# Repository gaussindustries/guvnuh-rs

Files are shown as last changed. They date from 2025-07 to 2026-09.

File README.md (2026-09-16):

# Guv'nuh — Micro-Grid Governor Control Platform

A Rust, bare-metal-to-browser control system for a laboratory micro-grid generator set. A hard-real-time STM32H753 governs the machine; an ESP32 bridges it to a Dioxus server and a desktop operator console. Built as the engineering centerpiece for [Gauss Industries](https://gaussindustri.es).

---

## What it does

Guv'nuh closes the loop on a self-excited induction generator (SEIG) driven by a variable-speed prime mover: it holds speed and frequency against changing electrical load, sheds load safely on fault, and streams a full electrical picture — per-phase voltage and current, real power, power factor, DC-bus state — to an operator in real time.

The architecture follows one principle: **the STM32 runs the machine; everything else observes and commands.** Safety-critical decisions (overspeed, load rejection, over-voltage/current) are computed and acted on locally, on-device, with no dependence on the network being up. The ESP32 relays; the server stores; the terminal analyzes. Comms can drop without the machine ever losing control.

---

## System architecture

```
  ┌─────────────┐   UART/COBS    ┌──────────┐    TCP/COBS    ┌──────────────┐   HTTP    ┌───────────────┐
  │  STM32H753  │◄──────────────►│  ESP32   │◄──────────────►│ Dioxus Server│◄─────────►│ Desktop Term. │
  │  (RTIC 2)   │  telemetry ▲   │ (Embassy)│  telemetry ▲   │   + SurrealDB│           │  (Dioxus)     │
  │  the machine│  commands  ▼   │  bridge  │  commands  ▼   │   store/API  │           │  operator UI  │
  └─────────────┘                └──────────┘                └──────────────┘           └───────────────┘
        │
        ├─ dual ADS131M04 (3-phase V/I + DC bus) — coherent sampling
        ├─ TIM1 PWM → prime-mover drive
        ├─ TIM2 QEI → speed encoder
        └─ ordered load bank (2-step resistive, series-ground)
```

**One wire format, end to end.** Every hop serializes the same `shared` crate types with `postcard` + COBS framing — no translation layers, no schema drift between tiers (the whole set rebuilds together when the wire types change).

---

## The STM32H753 firmware — the real-time core

Written against **RTIC 2**, priority-scheduled so the machine stays in tolerance regardless of what else is happening:

| Priority | Task | Rate | Job |
|---|---|---|---|
| 3 | ADC DRDY ISR | ~4 kSPS | Read both ADCs coherently, accumulate sum-of-squares |
| 3 | UART4 RX ISR | event | Drain FIFO, COBS-decode commands into a queue |
| 2 | Safety supervisor | 500 Hz | Overspeed trip + fast electrical protection + load-rejection detection |
| 1 | Control loop | 100 Hz | Governing, full ADC finalize, telemetry assembly |

**Three-phase electrical measurement.** Two ADS131M04 24-bit delta-sigma ADCs share one SPI bus with tied SYNC lines, so all eight channels sample the *same instant* — essential for real-power math (V×I per phase must be coherent). The STM32 computes only the control-critical scalars locally (RMS V/I, real power, PF, frequency, DC bus); harmonics and deep analysis are left to the terminal. Sample rate is a single tunable constant, sized against measured worst-case execution time.

**Load rejection — the fast local path.** A sudden real-power drop means the generator has been unloaded and will overspeed (the defining hazard for a turbine prime mover). The 500 Hz supervisor watches total real power and reacts in-loop — shedding load and faulting — with no network round-trip. This is why the electrical measurements live on the STM32 and not just in telemetry.

**Ordered load bank.** A two-step resistive bank whose second stage draws its ground return *through* the first, so the switching order is a hard electrical constraint. The firmware models this as a state machine that makes an invalid state unrepresentable: it refuses to engage step 2 without step 1, sheds gracefully (2 then 1) under normal operation, and sheds immediately (open 1, dropping both) on E-stop or fault.

---

## The ESP32 bridge

An **Embassy** async firmware that does one job well: shuttle framed bytes between the STM32's UART and a TCP socket to the server, intercepting the link-layer handshake locally so a reboot on either side re-syncs without disturbing the machine. Deliberately dumb — it holds no control logic, matching the "STM32 runs the machine" principle.

---

## Server & operator console

**Dioxus fullstack server** (axum + SurrealDB): ingests telemetry over TCP, stores trials, and exposes a hardware-control API. Telemetry x-axes are derived from a **server-side frame index**, not the device clock — eliminating boot-offset artifacts by construction.

**Desktop operator terminal** (Dioxus): live governing controls (manual / open-loop / closed-loop / scripted profiles), real-time charts (RPM, three-phase voltage and current on shared axes, power and phase-alignment error), a load-bank panel that mirrors the firmware's ordered state machine in the UI, and a trials browser that replays any recorded run with every electrical channel toggleable.

**Scripted profiles** let an operator define an RPM trajectory with load steps scheduled at specific breakpoints — "at t=5s apply half load, at t=10s go full, at t=15s shed" — executed on-device with the ordered switching still enforced.

---

## Tech stack

- **Firmware:** Rust, `no_std`, RTIC 2 (STM32H753), Embassy (ESP32)
- **Wire format:** `postcard` + COBS over UART and TCP; shared type crate
- **Server:** Rust, Dioxus fullstack, axum, SurrealDB (raw HTTP transport)
- **Terminal:** Rust, Dioxus desktop
- **Sensing:** dual TI ADS131M04, external 8.192 MHz coherent clock
- **Networking:** WireGuard-gated admin plane, nginx reverse proxy

---

## Status

Operational: full command + telemetry pipeline live across all four tiers; load bank commanding end-to-end with ordered-switching and E-stop shedding verified in hardware; governing loop running closed on the bench. Three-phase ADC front-end is wired into the firmware (flag-gated) and pending analog front-end bring-up.

**Roadmap:** phase-lock to a grid reference (the alignment view is built and waiting), EtherCAT fieldbus, a SIL-2 certification path, and a micro steam turbine prime mover.

---

## License

© Gauss Industries. All rights reserved.

*Integrity · Innovation · Invention*

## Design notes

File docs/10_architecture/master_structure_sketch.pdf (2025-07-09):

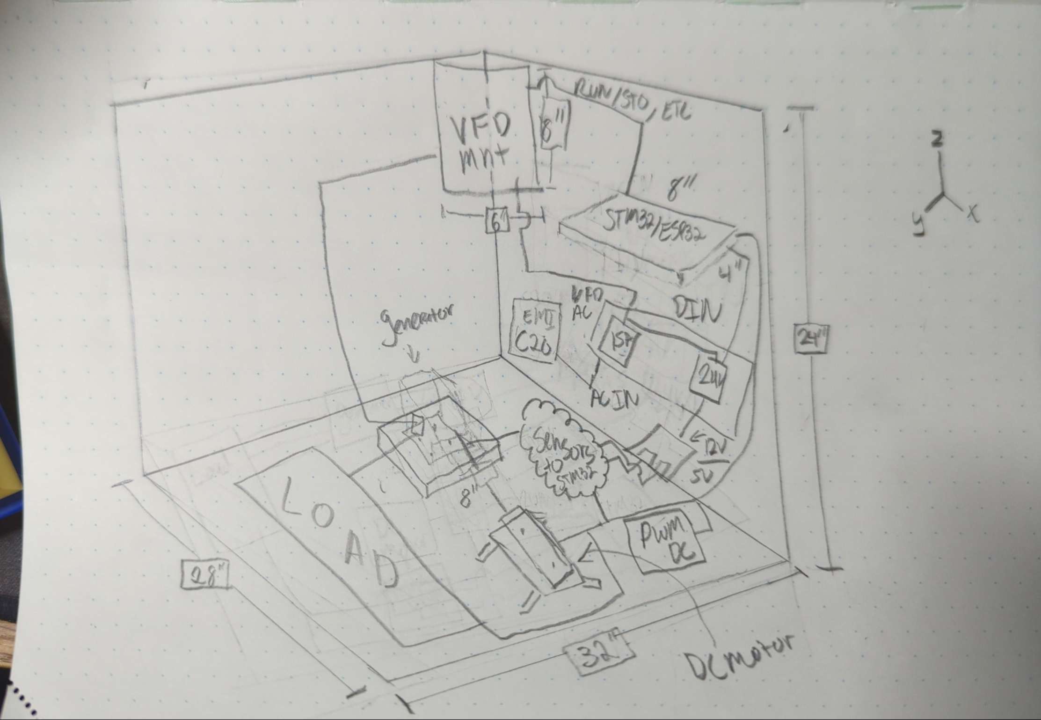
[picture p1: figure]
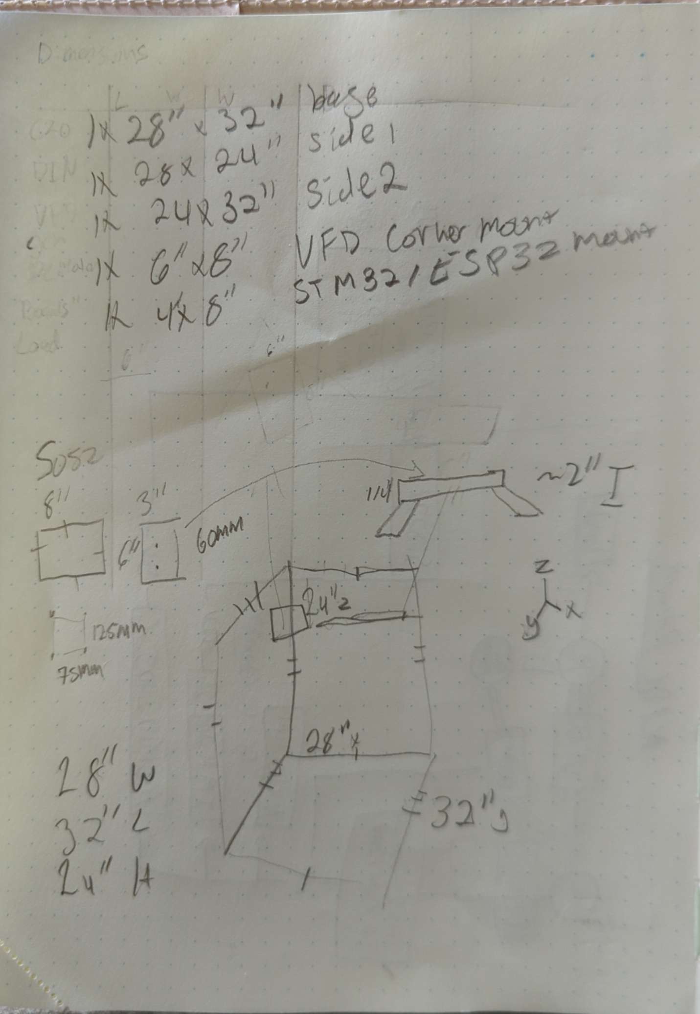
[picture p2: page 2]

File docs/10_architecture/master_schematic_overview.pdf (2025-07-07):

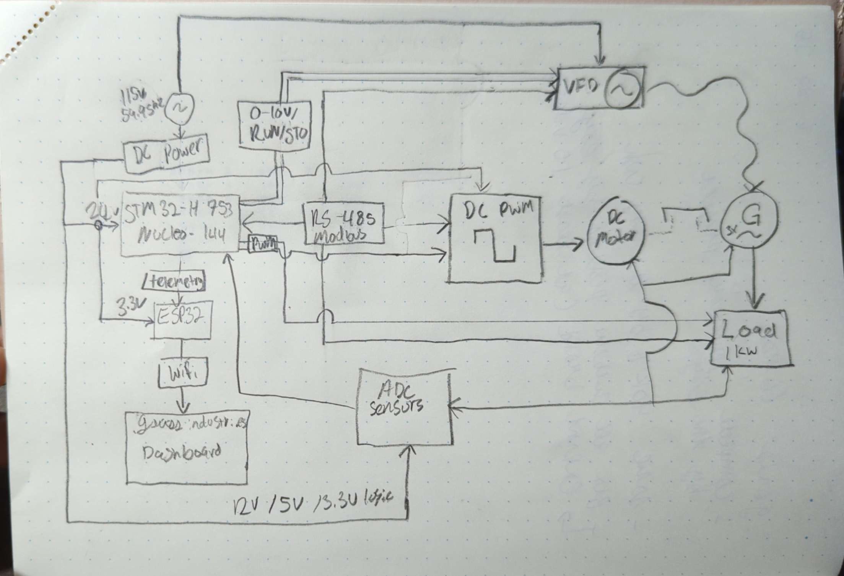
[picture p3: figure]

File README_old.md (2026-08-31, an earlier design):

# Guv'nuh – Resilient Micro-Grid Control Platform

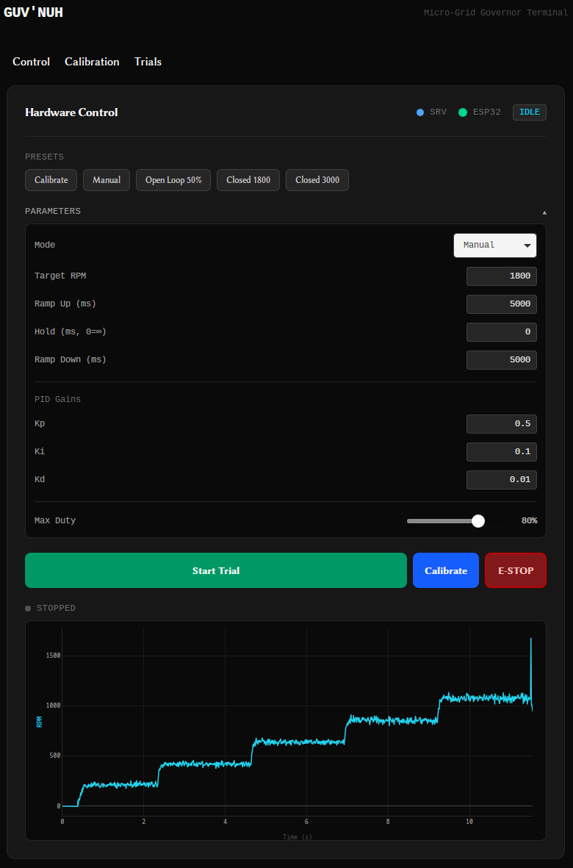
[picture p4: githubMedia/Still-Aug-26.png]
Guv'nuh Alpha Preview

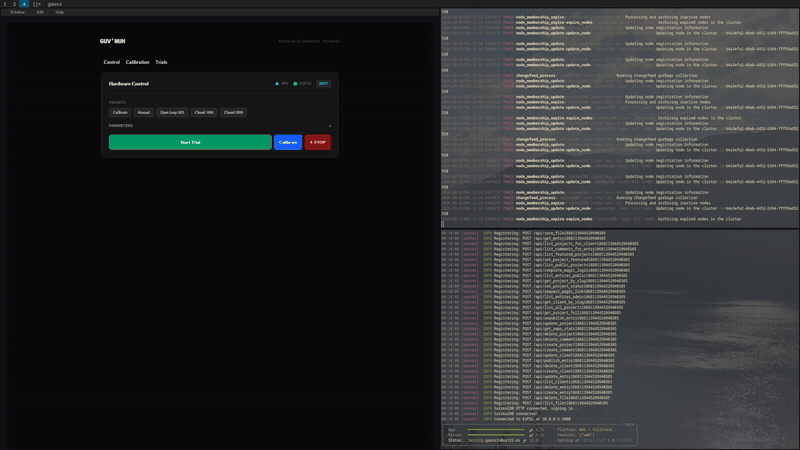
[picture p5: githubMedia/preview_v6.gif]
Guv'nuh Live Demo

> This is showing the calibration step, please see below for HQ screen shot

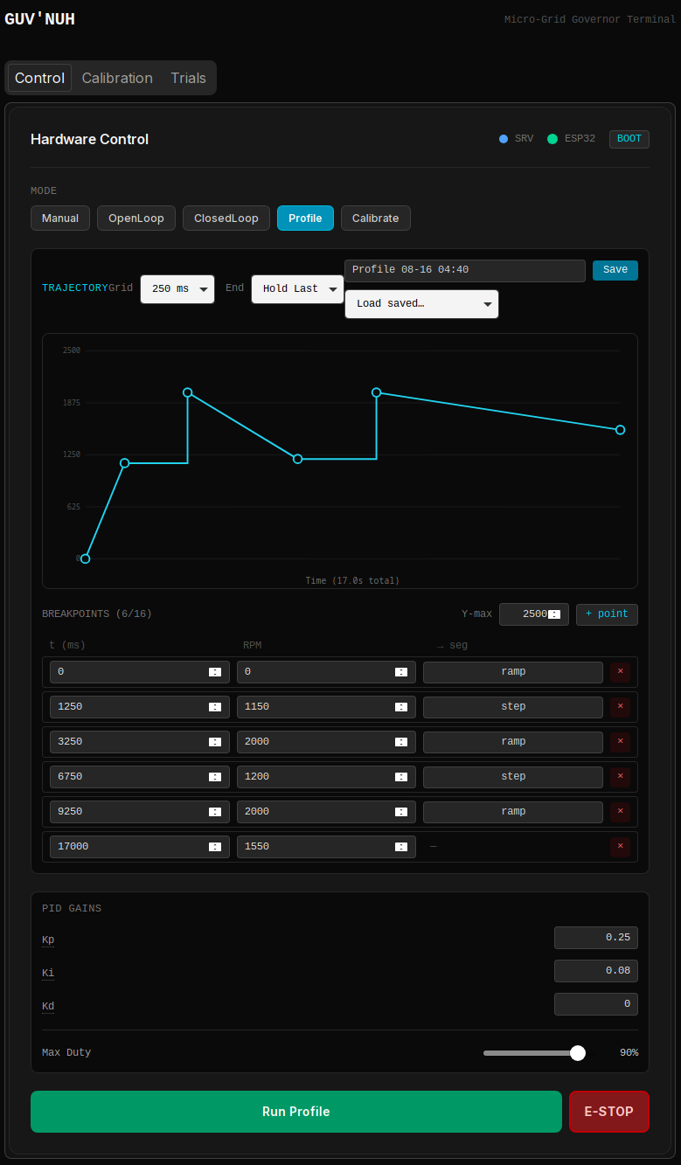
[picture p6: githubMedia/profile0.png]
Guv'nuh Chart Profile Showcase

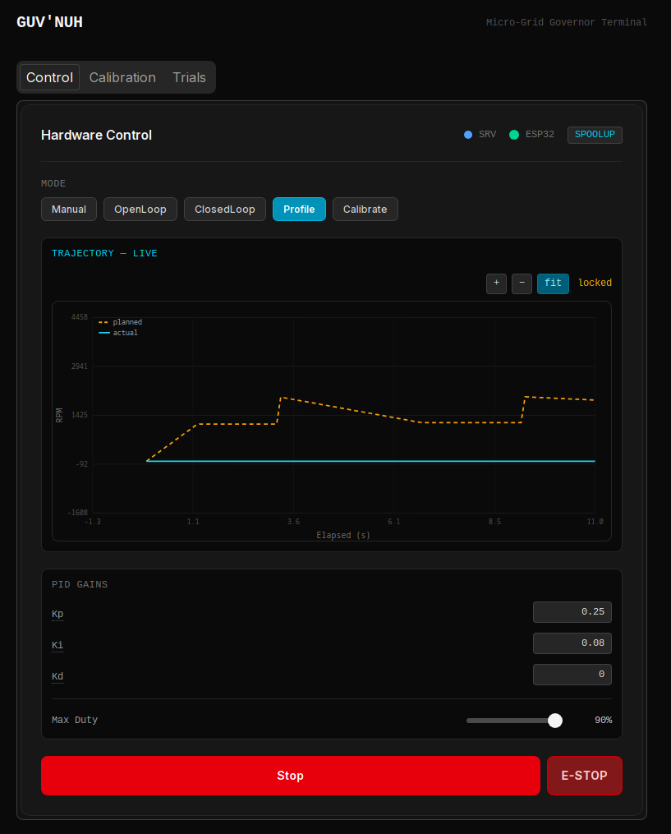
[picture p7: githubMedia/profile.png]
Guv'nuh Chart Profile Showcase


> This is showing the profile being executed showing planned vs actual rpm in this case

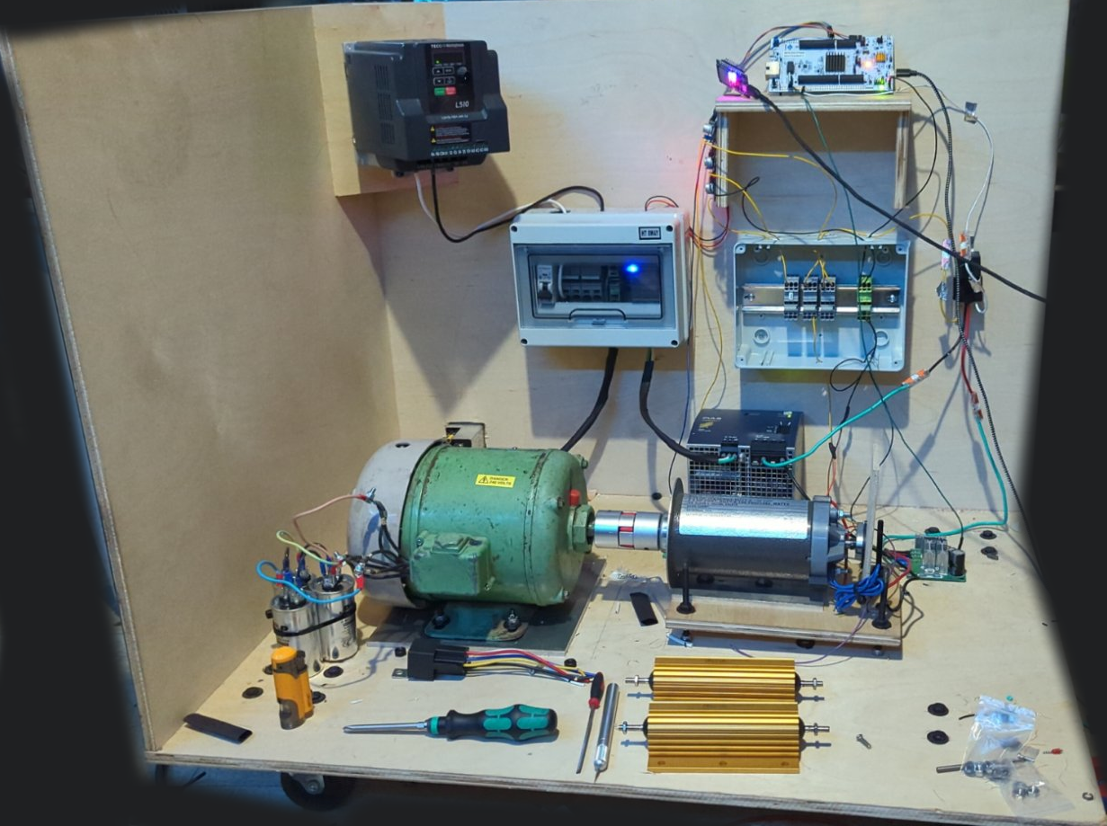
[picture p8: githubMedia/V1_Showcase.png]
Guv'nuh Showcase

> August 13th (this is going to be as tidy as the left hand side once completed)

A laboratory-scale governor architecture that drives a DC prime mover coupled to a
**self-excited induction generator**, forming a secure, programmable micro-generator
testbed. This platform demonstrates a "Zero-Trust" industrial control loop, fusing
hard real-time safety (STM32/RTIC) with secure cloud telemetry
(Rust/Dioxus/SurrealDB).

---

## Project Purpose

> To engineer a governor reference design that decouples **Physics** (safety
> critical) from **Connectivity** (telemetry), demonstrating the complete
> engineering pipeline from firmware to cloud SCADA — with the architecture
> designed against IEC 61508 and IEEE 1547 as guiding standards, and explicitly
> structured so the DC-motor testbed can be swapped for a real prime mover
> (Phase 4 turbine) with no fundamental firmware changes.

---

## Functional Scope

### Phase 1 — Governor Brains (Current)

| ID | Requirement | Target Value | Status |
| --- | --- | --- | --- |
| **F-01** | Closed-loop speed regulation (PID) | ±2% droop, 0–1 kW range | 🔄 In Progress |
| **F-02** | Overspeed trip to safe state | Software supervisor @ 500 Hz (hardware trip planned) | ✅ Software / 📋 Hardware |
| **F-03** | Load Rejection Response | Recovery < 2s (load step) | 🔄 In Progress |
| **F-04** | Re-entrant MCU Handshake | Either device re-syncs on reboot, any order | ✅ Complete |
| **F-05** | Telemetry Segregation | "Air-gapped" UART Link | ✅ Complete |
| **F-06** | Intranet Telemetry Stream | Live Telemetry over TCP/WiFi | ✅ Complete |
| **F-07** | Prelude-Based Run Configuration | `Configure(RunConfig)` before `Start` | ✅ Complete |
| **F-08** | Live Parameter Adjustment | Duty / RPM / PID gains adjustable mid-run | ✅ Complete |
| **F-09** | Interrupt-Driven Command RX | Overrun-free UART command reception | ✅ Complete |
| **F-10** | Trial Run Recording | Per-trial telemetry to SurrealDB | ✅ Complete |
| **F-11** | Telemetry Visualization | Custom SVG chart primitives, multi-series + metric toggles | ✅ Complete |
| **F-12** | REST Hardware API | Stateless control + data endpoints on :3001 | ✅ Complete |
| **F-13** | Duty→RPM Calibration | On-device least-squares fit with validation | ✅ Complete |
| **F-14** | Feedforward Control | Calibration coefficient seeds PID duty | ✅ Complete |
| **F-15** | Calibration Reporting | Fit + raw points persisted, drift-tracked | ✅ Complete |
| **F-16** | Independent Safety Supervisor | Preemptive overspeed + sensor-plausibility trip, comms-independent | ✅ Complete |
| **F-17** | Fault History & Auto-Close | Faults persisted per-trial; faulted trials self-close | ✅ Complete |
| **F-18** | Setpoint-Profile Trajectories | Sparse `(t, target)` breakpoints executed on-device; commanded-vs-actual overlay | ✅ Complete |
| **F-19** | Profile Library | Named profiles persisted to SurrealDB, upsert-by-name, load into editor | ✅ Complete |
| **F-20** | Prime-Mover Abstraction | `PrimeMover` trait decouples control from actuator (DC motor ↔ turbine) | ✅ Complete |
| **F-21** | Deadline Monitoring | Per-state execution-time budget; trips `DeadlineMiss` fault on sustained overrun | ✅ Complete |

### Phase 2 — EtherCAT Integration

Replaces the UART telemetry link with an EtherCAT fieldbus, enabling
deterministic sub-millisecond communication between the Governor and
downstream field devices. This phase targets industrial interoperability
and positions the platform against real SCADA deployments.

### Phase 3 — 48V Storage Converters

Integrates bidirectional DC-DC converters for a 48V battery storage bank,
enabling islanded operation, load leveling, and grid-forming capability.
Adds a second control loop for state-of-charge management alongside the
existing speed governor.

### Phase 4 — Micro Steam Turbine *(Future Reference)*

> ⚠️ High temperature and pressure — deferred until Phase 1 control logic
> is fully validated and hardened.

Replaces the DC motor testbed with a purpose-built micro steam turbine as
the prime mover, completing the generator set. The Governor architecture
is designed from the ground up to support this transition — the layered
separation (independent safety supervision, prime-mover abstraction,
prime-mover-agnostic control, guard-conditioned sequencing) means the
turbine is a prime-mover swap plus sensor growth, not a rewrite. The
calibration architecture anticipates this fork: the device fits only the
simple relationship it needs to control autonomously, while the server
retains raw sample points for richer analysis (nonlinear maps, drift) that
can evolve without reflashing.

---

## Hardware Under Control

The testbed is a two-machine set, deliberately chosen so the control problem
mirrors a real generator:

- **Prime mover:** a 100 V / 2 HP continuous DC motor, PWM-driven through a
  motor controller, mechanically coupled to the generator shaft. Reaches
  ~2500 RPM at 100% duty. The AMT102-V encoder (QEI, 8192 counts/rev) is the
  speed feedback.
- **Generator:** a 1/2 HP three-phase AC **induction** machine used as a
  generator — nameplate 230 V / 460 V, 1720 RPM full-load (a 4-pole machine,
  1800 RPM synchronous → 60 Hz target). Because it has no permanent magnets, it
  is a **Self-Excited Induction Generator (SEIG)**: it produces only residual
  millivolts when spun bare, and builds real voltage only once a capacitor bank
  across its terminals bootstraps self-excitation. Holding shaft speed at
  1800 RPM holds both 60 Hz and (with stable excitation) the target voltage —
  which is precisely the governor's job.

This is why the `EXCITE` state exists and why voltage/frequency sensing is the
gating next step: the generator's real output only appears once excited, and the
sequencing states advance on measured conditions, not just spin.

---

## [System Architecture (Click me!)](https://kicanvas.org/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 "Click me to view Schematics Online!")

```
┌──────────────────────────────────────────────────────────────┐
│                       SAFETY DOMAIN                          │
│                                                              │
│   AMT102-V Encoder ──► STM32H753 (RTIC)                     │
│   INA240 + ADS131M04 ──► (voltage/current front-end — WIP)  │
│                          ├── Safety Supervisor (pri 2, 500Hz)│
│                          │     preemptive overspeed + sensor │
│                          ├── State Machine (14 states, pri 1)│
│                          ├── PID Loop + Feedforward          │
│                          ├── Calibrator (duty→RPM fit)       │
│                          ├── Ramp Generator                  │
│                          ├── MotorController (inverted PWM)  │
│                          ├── UART4 RX ISR (cmd decode, pri 3)│
│                          └── UART TX/RX ──────────────┐      │
└───────────────────────────────────────────────────────┼──────┘
                                                        │ UART
┌───────────────────────────────────────────────────────┼──────┐
│                    TELEMETRY DOMAIN                   │      │
│                                                       ▼     │
│   ESP32-WROOM ◄──── UART RX (GPIO16)                        │
│       ├── Re-entrant Handshake (Hello/HelloAck, framed)     │
│       ├── WiFi (esp-wifi + embassy-net)                      │
│       ├── TCP Server :3000 (bidirectional) ──────────────►  │
│       └── CMD forwarding (TCP → UART → STM32)                │
└──────────────────────────────────────────────────────────────┘
                                          │ TCP/WiFi
┌─────────────────────────────────────────▼────────────────────┐
│                     COMMAND DOMAIN                            │
│                                                              │
│   gaussindustri.es Server (Dioxus Fullstack + Axum)          │
│       ├── ingest_loop: ESP32 TCP → postcard/COBS decode      │
│       ├── Uplink demux: Telemetry / Calibration / handshake  │
│       ├── frame sanity gate: reject non-finite / OOR values  │
│       ├── fault detect → mark + auto-close trial             │
│       ├── SurrealDB: trial + telemetry + calibration storage │
│       ├── live_buffer: frame-indexed ring for polling        │
│       └── REST API :3001 (hardware control + trial data)     │
│                                                              │
│   Desktop Terminal (Dioxus Desktop)                          │
│       ├── Tabs: Control / Calibration / Trials               │
│       ├── Mode-Driven Console: setpoint source swaps by mode │
│       │     Manual / OpenLoop / ClosedLoop / Profile / Cal   │
│       ├── Profile Editor: draggable SVG trajectory + library │
│       ├── Trial Control: Configure→Start / Stop / E-Stop     │
│       ├── Clear Faults: recover FAULT/ESTOP → IDLE           │
│       ├── Live Control: real-time duty adjustment (Manual)   │
│       ├── Calibration Panel: fit stats + points + fit chart  │
│       ├── Connection Status: ESP32 + Server + STM32 state    │
│       ├── Trials Dashboard: accordion list + fault strip     │
│       └── Custom SVG Charts: LineChart + ScatterChart,       │
│             viewport zoom/pan, RPM/V/I/Freq/Temp/DC Bus      │
└──────────────────────────────────────────────────────────────┘
```

### 1. The Governor (STM32H753 + RTIC)

- **Role:** The "Physics Engine."
- **Responsibility:** Independent safety supervision, state machine, PWM motor
  control, encoder RPM sampling, duty→RPM calibration, feedforward + PID control,
  command reception.
- **Safety Supervisor:** A dedicated **priority-2 task at 500 Hz** (five times
  the control loop) monitors overspeed and sensor plausibility using only local
  sensors — no dependency on the ESP32 or server. On an overspeed or an
  implausible (non-finite / out-of-range) RPM reading it forces the motor and
  relay off and slams the machine to `FAULT`, **preempting** the priority-1 state
  machine. The trip ceiling is a `#[shared]` value defaulting to a compiled-in
  safe constant (active from boot with zero config); a server-commanded limit is
  clamped to compiled absolute bounds, so the operator can tune within safety but
  never disable it, and comms loss never removes protection. This is the layer
  that keeps the machine safe even when everything upstream is dead — the
  foundation for a hardware-level overspeed trip (the eventual SIL-2 safety of
  last resort). Recovery sequencing stays in the state machine; the supervisor
  owns only the preemptive trip.
- **Command Reception:** A dedicated **UART4 RX interrupt** (priority 3) drains
  the FIFO the instant bytes arrive, accumulates COBS frames, decodes them into
  `Command`s, and hands them to the priority-1 state machine through a
  `heapless::Deque` queue. This decouples reception speed from the 10 ms control
  tick and eliminates FIFO overrun on multi-byte command frames.
- **Calibration:** A `CALIBRATE` run steps through a fixed set of duty levels,
  lets RPM settle at each, and computes a least-squares `duty → RPM` line
  (slope `k`, intercept, r²) using Welford accumulation for per-point mean and
  standard deviation. A validation gate (minimum r², positive plausible slope,
  per-point coefficient-of-variation ceiling) marks the fit `valid` or rejects
  it — a rejected fit is still reported but does not enable feedforward.
- **Feedforward:** When a valid calibration exists, closed-loop states compute a
  feedforward duty from `k` and the target RPM, so PID trims a small residual
  around an already-near-correct duty instead of integrating up from zero. The
  path is conditional — with no calibration, PID runs exactly as before.
- **Telemetry Task:** Reads the encoder, writes a shared `Measurements` struct,
  assembles a `Telemetry` frame from it, and drives the UART. A single-slot
  `pending_report` mailbox lets the `CALIBRATE` state hand a completed
  calibration report to the telemetry task (the sole owner of the transmitter)
  without two-task contention on `tx`.
- **State Machine:** `BOOT` → `IDLE` → `CONFIGURED` → *(mode-dependent)*, with
  a graceful `RAMP_DOWN` on stop and `FAULT` / `ESTOP` reachable from any state.
- **Re-entrant Handshake:** On boot the STM32 sends a framed `Uplink::Hello`,
  arms the RX interrupt, and proceeds to `IDLE` once a `HelloAck` arrives (or
  after a bounded retry, so a dead gateway never bricks it in `BOOT`). A `Hello`
  arriving mid-run — the gateway rebooting — is answered from *any* state with a
  `HelloAck` **without changing state**, so the machine keeps running while the
  link re-syncs. See "Link Handshake" below.
- **Motor Abstraction:** `MotorController` encapsulates the inverted-PWM logic
  (duty MAX = motor off) behind a `set_speed(fraction)` API with a configurable
  safety duty clamp.

### 2. The Gateway (ESP32-WROOM + esp-hal)

- **Role:** The "Scribe."
- **Responsibility:** Receives telemetry from the STM32 over UART, connects to
  WiFi, and streams data to TCP clients on port 3000. Forwards commands from
  the server back to the STM32 over UART. Participates in the re-entrant
  handshake: announces its own boot with a framed `Command::Hello`, and answers
  the STM32's `Uplink::Hello` locally with a `Command::HelloAck` (no server
  round-trip), so either device can reboot in any order and the link re-syncs.
- **FIFO Draining:** The UART→TCP bridge drains all available bytes per loop
  iteration rather than one byte at a time, so it keeps pace with the 100 Hz
  telemetry stream and the burst of a calibration report without overrunning the
  ESP32's RX FIFO (which would corrupt frames mid-flight).
- **Isolation:** Connected via UART only. The ESP32 cannot directly access
  any Governor control variables — all communication is through a sanitized
  COBS message protocol. The gateway is a dumb byte pipe: it forwards frames
  without interpreting their contents (it peeks only for the framed handshake
  messages), so the wire format can evolve with near-zero gateway changes.

### 3. The Server (Dioxus Fullstack + Axum + SurrealDB)

- **Role:** The "Command Center."
- **Ingest Loop:** Connects to ESP32 over TCP, decodes postcard/COBS frames as
  an `Uplink` enum, and demultiplexes: `Telemetry` frames flow to the live
  buffer and (during a trial) to SurrealDB; `Calibration` frames are persisted
  as calibration records; handshake frames are tolerated and ignored (they are
  normally intercepted at the gateway). A sanity gate rejects telemetry with
  non-finite or physically impossible values so transient wire corruption never
  reaches storage or the chart.
- **Trial System:** Each trial run creates a `trial` record with start/stop
  timestamps, frame count, and status. Telemetry frames are tagged with
  `trial_id` for isolated retrieval.
- **Fault Handling:** When a telemetry frame carries a fault, the server marks
  the trial's status `fault`, records the fault name and stop time, counts the
  frames, and clears the active-trial flag — the trial **auto-closes** on the
  first fault frame (the hardware has already stopped itself via the supervisor,
  so only the record-keeping half of a normal stop runs). Trial-completion logic
  is guarded so a graceful stop never overwrites a `fault` status.
- **Calibration Store:** A completed calibration is stored as a `calibration`
  record — the fit (`k`, intercept, max RPM, r², valid flag) **and** the raw
  sample points (duty, mean RPM, standard deviation, sample count), tagged with
  `rig_id` and the originating `trial_id`. Storing both the reduced fit and the
  raw acquisition mirrors a calibration certificate: the fit is the conclusion,
  the points are the evidence, and successive records reveal mechanical drift.
- **Live Buffer:** A frame-indexed ring buffer feeds the desktop's polling
  chart with a monotonic `ts_s` x-axis derived from frame index (100 Hz), so
  the trace is independent of the STM32 boot clock.
- **Database Transport:** Trial-status writes go over raw HTTP to SurrealDB's
  `/sql` endpoint (the SDK's `/rpc` query transport is unreliable on the current
  setup); a shared helper in the DB module carries the auth and namespace
  headers.
- **REST API (`:3001`):** Stateless hardware control and data query endpoints
  consumed by the desktop terminal.

### 4. The Desktop Terminal (Dioxus Desktop)

- **Role:** The "Operator Console."
- **Tabbed Layout:** Control, Calibration, and Trials, each a focused panel.
- **Mode-Driven Control Console:** One console where the selected **mode**
  (Manual / OpenLoop / ClosedLoop / Profile / Calibrate) is the *setpoint
  source* — the panel swaps only the setpoint-editor region while the status
  bar, PID gains, max-duty clamp, and run controls stay constant. PID gains
  carry hover tooltips explaining each term; a named **preset** can be applied
  with one click. The full `RunConfig` is sent as a prelude before the run.
- **Setpoint-Profile Editor:** In Profile mode, a custom draggable SVG chart
  defines a speed trajectory as sparse `(t, target)` breakpoints with per-
  segment interpolation (linear ramp or step hold) and an end behavior (hold /
  stop / loop). The profile — not ramp/hold timings — owns the run's timing.
  A bidirectional breakpoint table edits the same points. When a profile runs,
  the chart switches to a **commanded-vs-actual overlay**: the planned
  trajectory (dashed) over the live actual RPM (solid), elapsed-time aligned, so
  the PID's tracking of the curve is visible in real time.
- **Profile Library:** Named profiles are saved to SurrealDB (upsert-by-name)
  and loaded back into the editor from an inline picker, with a confirm dialog
  guarding unsaved edits. The library stores the real breakpoints; the fixed-
  size array padding is a firmware-wire concern only.
- **Trial Control:** Start sends `Configure` then `Start` (or pushes the profile
  then starts a closed-loop trial); Stop ramps down gracefully; a dedicated
  Calibrate mode runs the calibration routine; an always-available **E-Stop**
  kills the motor immediately. When the hardware is in `FAULT`/`ESTOP`, a
  **Clear Faults** button (state-gated on the live STM32 state) sends
  `ClearFaults` to return to `IDLE` before another run.
- **Live Control:** In Manual mode, a duty slider streams real-time
  `LiveAdjust(Duty)` commands to the motor while it runs.
- **Custom Chart Primitives:** All charting is done by two reusable in-house SVG
  components (no external charting library) — `LineChart` (multi-series, dual
  y-axis) and `ScatterChart` (markers + error bars + fit overlay). Both are
  **viewport-driven**: scroll to zoom (shift = X-only, ctrl = Y-only), drag to
  pan, double-click to reset, with an auto-follow mode that tracks live data
  until the operator interacts. A shared `ChartControls` widget provides zoom/fit
  buttons for any chart.
- **Calibration Panel:** Shows the latest fit with a validity banner, the fit
  statistics (`k`, intercept, max RPM, r²), the sampled points table, and a
  `ScatterChart` of the points with per-point standard-deviation error bars and
  the fitted line superimposed. A history table tracks the coefficient and fit
  quality across runs to surface mechanical drift over time.
- **State-Aware Trials:** The terminal reads the live STM32 state and closes a
  trial when the hardware returns to `IDLE` on its own, or when a fault
  auto-closes it server-side.
- **Trials Dashboard:** Accordion list of all recorded trials with status,
  timestamps, and frame counts. Faulted trials are flagged (red dot + badge),
  and each trial's detail shows a **fault strip** — every fault that occurred,
  edge-triggered, with the timestamp it tripped, aligned to the RPM trace.
  Charts export to **SVG** (vector) for reports.
- **Metric Toggles:** RPM, Voltage RMS, Current RMS, Frequency, Temperature,
  DC Bus Voltage — each independently toggleable with dual y-axes.
- **Export:** One-click **SVG** (vector) export of charts for reports and client
  deliverables — crisp at any scale, no raster dependency.

---

## State Machine

The Governor's behavior after `Start` is determined by the `RunMode` supplied in
the preceding `Configure` prelude:

```
BOOT ──► IDLE ──(Configure)──► CONFIGURED ──(Start)──┐
                                                     │
        ┌────────────────────────────────────────────┤
        │                                             │
   RunMode::Calibrate ──► CALIBRATE ──────────────────┤ (step duties → fit → report → IDLE)
   RunMode::Manual    ──► MANUAL ────────────────────┤ (live duty control)
   RunMode::OpenLoop  ──► SPOOLUP ───────────────────┤ (ramp, no feedback)
   RunMode::ClosedLoop──► SPOOLUP ───────────────────┤ (feedforward + PID on RPM)
   RunMode::Generate  ──► SPOOLUP ──► EXCITE ──► PLL_LOCK ──► READY ──► GENERATE
                                                                          │
                                                                   LOAD_REJECTION
                                                                          │
        Any running state ──(Stop)──► RAMP_DOWN ──► IDLE                  │
        Any state ──(EmergencyStop)──► ESTOP                             │
        Any state ──(overspeed / sensor / fault)──► FAULT               │
        FAULT / ESTOP ──(ClearFaults | Stop)──► IDLE ◄───────────────────┘
```

`CALIBRATE`, `OpenLoop`, and `ClosedLoop` are validated on hardware today, with
feedforward from calibration feeding the closed-loop path, and the independent
safety supervisor arming an overspeed trip from boot. The full generator sequence
(`EXCITE → PLL_LOCK → READY → GENERATE → LOAD_REJECTION`) is scaffolded with
time-based placeholders pending the ADC voltage/current/frequency front-end; the
`EXCITE` state's real role is capacitor self-excitation of the SEIG, advancing on
measured voltage build-up once that sensing lands.

**Safety layering.** The state machine sequences *operation*; a separate,
higher-priority supervisor enforces *safety* independently. `EmergencyStop` and
overspeed/sensor trips are honored from any state and force the machine safe
before the sequencer runs. Comms loss is deliberately **not** a trip: an off-grid
prime mover must run autonomously (a "heartbeat-or-stop" rule would be a deadly
embrace when the generator is charging the very system that sends the heartbeat),
so the machine degrades to autonomous operation on last-known-good config and
local safety, and the link re-syncs opportunistically when the gateway returns.

---

## Link Handshake

STM32↔ESP32 link establishment is a framed, in-protocol, event-driven handshake —
**not** a heartbeat. It is sent on (re)start and acknowledged; its absence does
nothing (the machine runs autonomously), its presence re-establishes the link.

- **`Hello` / `HelloAck`** are carried in both `Command` (inbound to the STM32)
  and `Uplink` (outbound), so the exchange is symmetric: whoever boots announces
  with `Hello` in its outbound direction, whoever is running replies `HelloAck`.
- **STM32 reboots:** it sends `Uplink::Hello`; the running gateway answers
  `Command::HelloAck` locally. (Old failure mode — STM32 stuck in `BOOT` waiting
  for an `OK` the running gateway would never re-send — is gone.)
- **ESP32 reboots:** it sends `Command::Hello`; the running STM32 answers
  `Uplink::HelloAck` from whatever state it is in, without disturbing operation.
  (Old failure mode — gateway stuck waiting for a `HELLO` the running STM32 would
  never re-send — is gone.)
- The handshake flows through the same COBS/ISR decode path as every other
  message, so it never contends with the raw-byte polling the old ASCII
  handshake required. Either device can be reflashed or power-cycled in any order
  and the link re-syncs on its own.

---

## Calibration & Feedforward

A `CALIBRATE` run characterizes the prime mover and feeds the result back into
control:

1. **Acquisition.** The `Calibrator` holds each of several duty levels for a
   settling period, then samples RPM over a tail window — accumulating mean and
   standard deviation per point via Welford's method (no sample buffering).
2. **Fit.** A least-squares line through the `(duty, mean RPM)` points yields
   the coefficient `k` (RPM per unit duty), the intercept, and r². Extrapolating
   to duty = 1.0 gives a practical max RPM.
3. **Validation.** The fit is accepted only if r² clears a floor, the slope is
   positive and plausible, and every point's coefficient of variation is within
   a ceiling. Low-duty points near the friction floor are the usual failure
   mode — the same absolute encoder noise is a larger *fraction* of a small RPM,
   so the sampled duty band starts above the friction floor and the CV ceiling is
   tuned to reject genuinely noisy points without rejecting honest low-RPM ones.
   A rejected fit is still reported, but does **not** enable feedforward.
4. **Feedforward.** With a valid fit, closed-loop states command a feedforward
   duty derived from `k` and the target RPM; PID then trims the small remaining
   error. The integrator no longer crawls up from zero, which sharpens the
   response — the value of measuring `k` in the first place. (Gains are re-tuned
   *lower* with feedforward active, since PID now corrects only a small residual.)

**Division of labor.** The device computes only the simple linear fit it needs
to control autonomously (a control loop cannot depend on a network round-trip),
and holds it in shared state for feedforward. It reports the raw sample points
upward so the server can perform richer analysis — nonlinear fits, outlier
rejection, drift comparison across runs — and eventually push a lookup table
back down via the `Configure` prelude, all without reflashing firmware attached
to a spinning mass. This is the seam the Phase 4 turbine fork is built around.

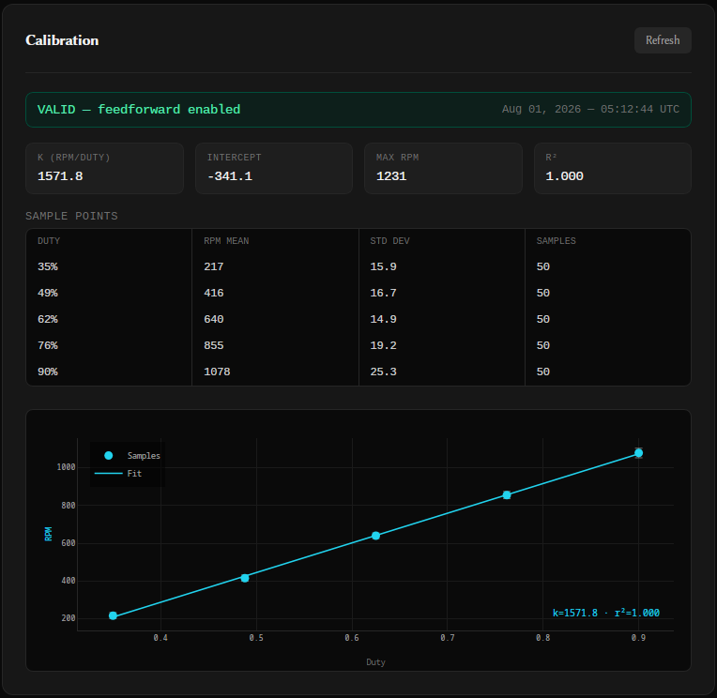
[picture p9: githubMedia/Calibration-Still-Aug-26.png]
Calibration Example


---

## Timing & Determinism

The control architecture is instrumented for hard-real-time timing analysis and
enforces its own execution-time deadlines.

### Cycle-accurate measurement

The 100 Hz control loop is instrumented with the Cortex-M7 cycle counter
(`DWT->CYCCNT`, enabled at boot) to measure **per-state execution time**. Each
iteration's elapsed cycles are recorded into a per-state table (max + mean),
giving the observed worst-case execution time of every state at 64 MHz sysclk.

> **Scope, stated precisely:** these are **measurement-based** figures — the
> *maximum observed* execution time over many iterations — not a statically
> proven WCET bound (which would require a pipeline-aware analyzer modelling the
> M7's ART accelerator, branch prediction, and flash wait-states — a planned
> step toward the SIL-2 target). The distinction is deliberate: the numbers are
> honest observations, not guarantees.

### Deadline monitoring & fail-safe (`DeadlineMiss`)

Beyond measuring, the firmware **enforces** timing. Each control iteration's
execution time is checked against a **per-state deadline budget** — a
configurable fraction of the loop period (`DEADLINE_BUDGET_FRAC`, default 80 %),
leaving headroom for the priority-2 safety supervisor's preemption, the UART RX
ISR, and jitter. Only time-critical states carry a deadline (SPOOLUP → GENERATE,
CALIBRATE, MANUAL); BOOT / IDLE / CONFIGURED / FAULT / ESTOP are exempt.

If a deadline-bearing state overruns its budget for `DEADLINE_MISS_STREAK`
(default 3) **consecutive** iterations — a *sustained* degradation, not a
single-sample blip — the firmware trips a `Fault::DeadlineMiss` through the same
fault path as any other trip: motor de-energized, relay open, → `FAULT`. The
consecutive-streak filter is deliberate: a safety check that nuisance-trips on
one anomalous sample gets disabled in practice, which is worse than not having
it.

This is the RTOS deadline-monitoring concept realized on bare-metal RTIC — the
system watches its own real-time behaviour and fails safe when guarantees
degrade. It will not trip under current operation (the loop runs well within
budget), but the detector is **in place ahead of the failure mode**: once the
high-temperature / high-pressure operating regime introduces real timing stress
(sensor-read stalls, heavier control math under load), the response already
exists. Both the budget fraction and the overrun streak are compile-time
constants, tunable per deployment.

---

## REST API Reference

All endpoints served on `:3001`.

| Method | Endpoint | Description |
| --- | --- | --- |
| `GET` | `/api/hw/status` | ESP32 connection state, trial active, current trial ID |
| `POST` | `/api/hw/configure` | Send a `RunConfig` prelude without starting a trial |
| `POST` | `/api/hw/start` | Send `Configure` + `Start`, create trial record |
| `POST` | `/api/hw/adjust` | Send a `LiveAdjust(LiveParam)` while running |
| `POST` | `/api/hw/stop` | Send `Command::Stop`, close trial with frame count |
| `POST` | `/api/hw/clear` | Send `Command::ClearFaults`, return STM32 to `IDLE` |
| `POST` | `/api/hw/estop` | Send `Command::EmergencyStop`, mark trial estopped |
| `GET` | `/api/hw/live` | Poll live frames since a counter (frame-indexed) |
| `GET` | `/api/trials` | List all trials, newest first |
| `GET` | `/api/trials/{id}` | Single trial metadata + all telemetry frames |
| `DELETE` | `/api/trials/{id}` | Delete trial and associated telemetry frames |
| `GET` | `/api/calibration` | Latest calibration record (fit + points) |
| `GET` | `/api/calibration/history` | All calibration records, newest first (drift) |

---

## Data Flow

```
Desktop "Start Trial" → POST /api/hw/start (body: RunConfig)
  → send Command::Configure(RunConfig) → TCP → ESP32 → UART → STM32
      → STM32: IDLE → CONFIGURED
  → SurrealDB: CREATE trial record
  → send Command::Start → TCP → ESP32 → UART → STM32
      → STM32: CONFIGURED → (mode-dependent run state)

STM32 telemetry (100Hz) → UART → ESP32 → TCP → Server
  → postcard::from_bytes_cobs::<Uplink>()
    → Uplink::Telemetry(frame)
      → sanity gate (finite + in-range)
      → live_buffer::push_frame()   (feeds desktop chart)
      → SurrealDB: CREATE telemetry { trial_id, rpm, duty_percent, state, fault, ... }
      → if fault: mark trial 'fault', count frames, auto-close

STM32 calibration complete → Uplink::Calibration(report) → (same pipe)
  → Server: store_calibration
    → SurrealDB: CREATE calibration { rig_id, trial_id, k, intercept,
                                      max_rpm, r_squared, valid, points[...] }

Overspeed / sensor trip (STM32 safety supervisor, pri 2)
  → motor + relay forced off, state → FAULT (preempts state machine)
  → telemetry frame carries fault → server auto-closes trial
  → Desktop: Clear Faults → Command::ClearFaults → STM32 FAULT → IDLE

Desktop live duty drag (Manual) → POST /api/hw/adjust {"Duty": 0.3}
  → Command::LiveAdjust(Duty(0.3)) → TCP → ESP32 → UART → STM32

Desktop "Stop Trial" → POST /api/hw/stop
  → Command::Stop → TCP → ESP32 → UART → STM32: → RAMP_DOWN → IDLE
  → SurrealDB: UPDATE trial SET status='completed' (guarded: never overwrites 'fault')
```

---

## Wire Protocol

All firmware↔server communication uses **postcard** serialization with
**COBS** framing (0x00 delimiter). Uplink frames are wrapped in an `Uplink`
enum so a single byte stream carries telemetry, calibration reports, and the
link handshake; the gateway forwards them opaquely (peeking only for handshake
frames) and the server demultiplexes on decode.

```rust
// shared/src/models/telemetry/telemetry.rs

pub enum Uplink {
    Telemetry(Telemetry),
    Calibration(CalibrationReport),
    Hello,      // STM32 announces (re)start
    HelloAck,   // STM32 acknowledges the gateway's Hello
}

pub struct Telemetry {
    pub ts_ms: u32,
    pub state: STATE,
    pub rpm: f32,
    pub duty_percent: f32,
    pub v_gen_rms: f32,
    pub i_gen_rms: f32,
    pub freq_gen_hz: f32,
    pub theta_err_rad: f32,
    pub temp_c: f32,
    pub dc_bus_v: f32,
    pub run_mode: Option<RunMode>,
    pub fault: Option<Fault>,
}

// Emitted once when a CALIBRATE run completes. Fixed-size arrays only —
// shared is no_std, no heap. The server adds ids/timestamps on store.
pub struct CalibrationReport {
    pub ts_ms: u32,
    pub k_rpm_per_duty: f32,
    pub rpm_intercept: f32,
    pub max_rpm: f32,
    pub r_squared: f32,
    pub points: [CalPointWire; CAL_POINT_COUNT],
    pub point_count: u8,
    pub valid: bool,
}

pub struct CalPointWire {
    pub duty: f32,
    pub rpm_mean: f32,
    pub rpm_stddev: f32,
    pub samples: u32,
}

pub enum Command {
    Ping,
    Configure(RunConfig),   // prelude sent before Start
    Start,
    Stop,
    EmergencyStop,
    LiveAdjust(LiveParam),  // real-time parameter changes
    Set(Setpoints),         // legacy
    ClearFaults,
    Hello,                  // gateway announces (re)start
    HelloAck,               // gateway acknowledges the STM32's Hello
}

pub struct RunConfig {
    pub mode: RunMode,          // OpenLoop | ClosedLoop | Calibrate | Manual | Generate
    pub target_rpm: f32,
    pub ramp_up_ms: u32,
    pub hold_ms: u32,           // 0 = hold indefinitely until Stop
    pub ramp_down_ms: u32,
    pub pid: PidGains,          // kp, ki, kd, output_min, output_max
    pub max_duty_clamp: f32,    // 0.0–1.0 safety limit
    pub target_freq_hz: f32,
    pub target_v_rms: f32,      // setpoint for the future AVR loop (inert until ADC)
    pub max_amperage_clamp: f32,// protection limit for the future current sense (inert until ADC)
}

pub enum Fault {
    OverVoltage,
    UnderVoltage,
    OverCurrent,
    OverTemp,
    OverSpeed,          // supervisor overspeed trip
    NoExcitation,
    PllUnlock,
    SensorOutOfRange,   // supervisor sensor-plausibility trip
    CommLost,           // reserved — comms loss is NOT a trip (see Safety layering)
}

pub enum LiveParam {
    Duty(f32),
    TargetRpm(f32),
    PidGains(PidGains),
    MaxDutyClamp(f32),
    TargetFreqHz(f32),
    TargetVRms(f32),
}
```

---

## Technology Stack

| Layer | Implementation | Rationale |
| --- | --- | --- |
| **Safety Core** | Rust RTIC on STM32H753 | Zero-cost abstractions, data-race freedom |
| **Safety Supervisor** | Priority-2 RTIC task @ 500 Hz | Preemptive overspeed/sensor trip, comms-independent |
| **Determinism** | DWT cycle counter + per-state deadline budgets | Measured execution time; fail-safe trip on sustained overrun |
| **Command RX** | UART4 interrupt + heapless queue | Overrun-free reception, decoupled from control tick |
| **Link Layer** | Framed `Hello`/`HelloAck` over COBS | Re-entrant handshake; either device reboots, any order |
| **Calibration** | On-device least-squares + validation | Autonomous fit; raw points reported for richer server analysis |
| **Control** | Feedforward + PID + Ramp generator | Coefficient-seeded duty, closed-loop trim (tuning WIP) |
| **Telemetry Gateway** | esp-hal + embassy-net on ESP32 | no_std WiFi, memory-safe networking, opaque byte pipe |
| **Transport** | UART (3.3V) + TCP/WiFi | Hardware isolation between domains |
| **Backend** | Axum + SurrealDB (raw `/sql`) | Type-safe async Rust API |
| **Frontend** | Dioxus Fullstack + Desktop | Shared types from firmware to UI |
| **Visualization** | Custom SVG (in-house) | `LineChart` + `ScatterChart`, viewport zoom/pan, SVG export |
| **Desktop** | Dioxus Desktop + reqwest | Native operator console |
| **Safety (future)** | Hardware overspeed trip + Watchdog | Fail-safe torque-off independent of software (design target: SIL-2) |

---

## Repository Structure (Cargo Workspace)

```text
.
├── shared/                    ↳ Wire-safe data models (no_std, serde + postcard)
│   └── src/models/
│       ├── state/states.rs    ↳ STATE enum (14 states) + Fault enum
│       └── telemetry/         ↳ Uplink, Telemetry, CalibrationReport, Command,
│                                RunConfig, LiveParam, PidGains, CalPointWire
├── firmware/
│   ├── stm32/                 ↳ Hard Real-Time Governor (RTIC, no_std)
│   │   └── src/
│   │       ├── main.rs        ↳ State machine, safety supervisor, UART4 RX ISR,
│   │       │                    telemetry task, framed handshake
│   │       ├── models/        ↳ Measurements (shared sensor struct)
│   │       └── guv/
│   │           ├── prime_mover.rs ↳ PrimeMover trait (actuator abstraction seam)
│   │           ├── motor.rs      ↳ MotorController: impl PrimeMover (inverted PWM)
│   │           ├── turbine.rs    ↳ TurbineController skeleton (impl PrimeMover, stub)
│   │           ├── pid.rs        ↳ PID controller (anti-windup, hot-swap gains)
│   │           ├── ramp.rs       ↳ Linear ramp generator
│   │           ├── profile.rs    ↳ SetpointProfile + eval_profile (trajectory exec)
│   │           ├── wcet.rs       ↳ Per-state cycle-count timing + deadline budgets
│   │           ├── calibrate.rs  ↳ Calibrator: duty→RPM fit, validation, feedforward
│   │           └── states/       ↳ boot, calibrate, idle, estop, fault...
│   └── esp32/                 ↳ Telemetry Gateway (esp-hal, no_std)
│       └── src/main.rs        ↳ Framed handshake, WiFi, TCP server, UART bridge
├── gaussindustri.es/          ↳ Fullstack server + desktop terminal (Dioxus 0.7)
│   └── src/
│       ├── backend/           ↳ Axum REST API, SurrealDB (raw /sql), live buffer
│       ├── components/
│       │   └── chart.rs       ↳ LineChart + ScatterChart + Viewport + ChartControls
│       └── views/
│           ├── control.rs     ↳ Mode-driven console + profile editor + overlay
│           ├── trials.rs      ↳ Trials dashboard, custom charts, fault strip
│           └── calibration.rs ↳ Fit panel, ScatterChart with error bars
├── docs/
│   ├── 00_requirements/       ↳ Project Charter
│   ├── 45_µcu_reference/      ↳ STM32H753 + ESP32-WROOM datasheets
│   ├── 50_motor_drive_data/   ↳ INA240, ADS131M04, AMT102-V
│   └── 90_release_notes/      ↳ Roadmap
├── hardware/                  ↳ KiCad sources, BOMs (WIP)
├── githubMedia/               ↳ Preview images
└── ci/                        ↳ GitHub Actions (Cross-compile + Test)
```

---

## Current State (August 2026)

### Validated End-to-End on Hardware

- ✅ STM32H753 boots, asserts safe PWM state, enables relay
- ✅ Independent safety supervisor — preemptive overspeed + sensor-plausibility
     trip at 500 Hz, active from boot, comms-independent
- ✅ Cycle-accurate per-state execution timing (DWT->CYCCNT) — observed
     worst-case measured at 64 MHz
- ✅ Deadline monitoring — per-state execution-time budget (fraction-of-period)
     trips `Fault::DeadlineMiss` on sustained overrun, through the fault path
- ✅ Re-entrant `Hello`/`HelloAck` handshake — either device reboots in any order
     and the link re-syncs (reflash-friendly)
- ✅ AMT102-V rotary encoder reading RPM via QEI (TIM2)
- ✅ PWM motor control via TIM1 (inverted logic) behind `MotorController`
- ✅ Telemetry transmitted over UART to ESP32 (postcard/COBS, 100Hz)
- ✅ ESP32 connects to 2.4GHz WiFi via esp-wifi + embassy-net
- ✅ TCP server on port 3000 streams live telemetry to server
- ✅ ESP32 FIFO-draining UART bridge — no frame corruption under burst load
- ✅ Bidirectional pipeline — desktop commands forwarded to STM32
- ✅ Interrupt-driven UART4 command RX — no FIFO overrun on `Configure` frames
- ✅ Prelude-based configuration — `Configure(RunConfig)` gates `Start`
- ✅ RunMode branching — Calibrate / Manual / OpenLoop / ClosedLoop validated
- ✅ Duty→RPM calibration — on-device least-squares fit with r² + validation
- ✅ Calibration reporting — fit + raw points over `Uplink`, persisted to DB
- ✅ Feedforward control — valid calibration seeds closed-loop duty
- ✅ Live parameter adjustment — real-time duty control in Manual mode
- ✅ Graceful `RAMP_DOWN` on stop; immediate `EmergencyStop` path
- ✅ Server decodes `Uplink` frames with sanity gate, stores to SurrealDB
- ✅ Trial run system — start/stop from desktop, per-trial DB storage
- ✅ Fault history — faults persisted per-trial; faulted trials auto-close and are
     flagged in the dashboard with a per-trial fault strip
- ✅ Clear Faults from the terminal — recover `FAULT`/`ESTOP` → `IDLE`
- ✅ REST API on :3001 (status, configure, start, adjust, stop, clear, estop,
     live, trials, calibration)
- ✅ Desktop terminal — unified mode-driven console (setpoint source swaps by mode)
- ✅ Setpoint-profile system — on-device trajectory execution (`eval_profile`),
     draggable SVG editor, commanded-vs-actual live overlay
- ✅ Profile library — named profiles persisted to SurrealDB (upsert-by-name),
     loaded back into the editor with an unsaved-edits confirm dialog
- ✅ Prime-mover abstraction — `PrimeMover` trait decouples control from the
     actuator; `MotorController` implements it, turbine skeleton stubbed against it
- ✅ Custom SVG chart primitives — `LineChart` (multi-series, dual-axis) +
     `ScatterChart` (markers, error bars, fit); no external charting dependency
- ✅ Viewport zoom/pan on all charts — scroll-zoom (shift=X, ctrl=Y), drag-pan,
     auto-follow-then-lock, shared `ChartControls` widget
- ✅ Calibration panel — fit stats, points table, `ScatterChart` with error bars
- ✅ Trials dashboard with accordion, custom charts, metric toggles, fault strip
- ✅ SVG (vector) export for client reports

### In Progress

- 🔄 PID closed-loop tuning **with feedforward enabled** (gains re-tuned lower)
- 🔄 ADC sensing front-end — **INA240** (current, shunt) + **ADS131M04**
     (4-ch simultaneous-sampling ADC) into the `Measurements` struct. This is the
     keystone: it turns four currently-stubbed features real at once — the
     guard-conditioned transitions, real EXCITE sensing, the AVR loop
     (`target_v_rms`), and current limiting (`max_amperage_clamp`).
- 🔄 SEIG capacitor bank + rectifier + switched DC load (physical build) —
     gated on the incoming PSU; recalibrate **loaded** once built (current `k`
     was measured unloaded)
- 🔄 Full generator sequence (EXCITE / PLL_LOCK / READY / GENERATE) on measured
     conditions rather than time-based placeholders (follows the ADC front-end)
- 🔄 Load rejection detection + recovery logic
- 🔄 Live WebSocket telemetry dashboard (web frontend)
- 🔄 VPS deployment with TLS

### Planned

- 📋 Hardware-interrupt overspeed trip — safety of last resort, independent of any
     software (the eventual SIL-2 layer beneath the software supervisor)
- 📋 Server-settable overspeed ceiling (clamped to compiled bounds) with a red
     trip-line on the live chart
- 📋 Guard-conditioned state transitions over validated `Measurements` — the
     EXCITE→PLL_LOCK→READY predicates (deferred until measurable measurements
     exist, i.e. after the ADC front-end)
- 📋 Sensor validity tagging (per-reading valid/stale) for diagnostic coverage
- 📋 Dedicated `measurement` task (ADC sampling) feeding `Measurements`
- 📋 Server-computed nonlinear feedforward map pushed via `Configure` prelude

---

## Build & Flash

### Prerequisites

```bash
# STM32 toolchain
rustup target add thumbv7em-none-eabihf
cargo install probe-rs-tools

# ESP32 toolchain
cargo install espup espflash
espup install
. ~/export-esp.sh  # add to ~/.bashrc

# Server
cargo install dioxus-cli
```

### Environment

```bash
# firmware/esp32/.env
WIFI_SSID=your_ssid
WIFI_PASS=your_password
TCP_PORT=3000

# gaussindustri.es/.env
SURREAL_ENDPOINT=ws://127.0.0.1:8000
SURREAL_USER=root
SURREAL_PASS=root
SURREAL_NS=gaussindustries
SURREAL_DB=main
ESP32_ADDR=192.168.1.189:3000
```

### Run

```bash
# Terminal 1 — Database
surreal start --user root --pass root

# Terminal 2 — Server
cd gaussindustri.es && dx serve

# Terminal 3 — Firmware
cd 00_Guv'nuh
cargo stm32-flash
. ~/export-esp.sh && cargo esp32-flash

# Terminal 4 — Desktop Terminal
cd gauss-terminal && dx serve --platform desktop
```

### Verify

```bash
# Check ESP32 TCP
nc <esp32_ip> 3000

# Check REST API
curl http://localhost:3001/api/hw/status
curl http://localhost:3001/api/trials
curl http://localhost:3001/api/calibration

# Send a calibration prelude + start (example)
curl -X POST http://localhost:3001/api/hw/start \
  -H "Content-Type: application/json" \
  -d '{"mode":"Calibrate","target_rpm":0,"ramp_up_ms":5000,"hold_ms":5000,
       "ramp_down_ms":5000,"pid":{"kp":1.0,"ki":0.0,"kd":0.0,
       "output_min":0.0,"output_max":1.0},"max_duty_clamp":1.0,
       "target_freq_hz":60.0,"target_v_rms":120.0,"max_amperage_clamp":1.0}'
```

---

## Standards & Design Targets

The architecture is designed with the following standards as references. They
inform the safety life-cycle, interconnection behavior, and coding discipline —
they are design targets guiding development, not claims of certified compliance.

- **IEC 61508 (SIL-2)** – Functional safety life-cycle & diagnostics *(target)*.
  The independent, preemptive safety supervisor and the planned hardware
  overspeed trip are the first structural steps toward this; full diagnostic
  coverage and sensor-validity tagging are on the roadmap.
- **IEEE 1547** – Interconnection and interoperability of distributed energy resources
- **Rust 2024 / high-integrity guidelines** – Data-race freedom, `#![no_std]` firmware

---

© 2026 Juan Carlos Mancilla Jr · MIT License

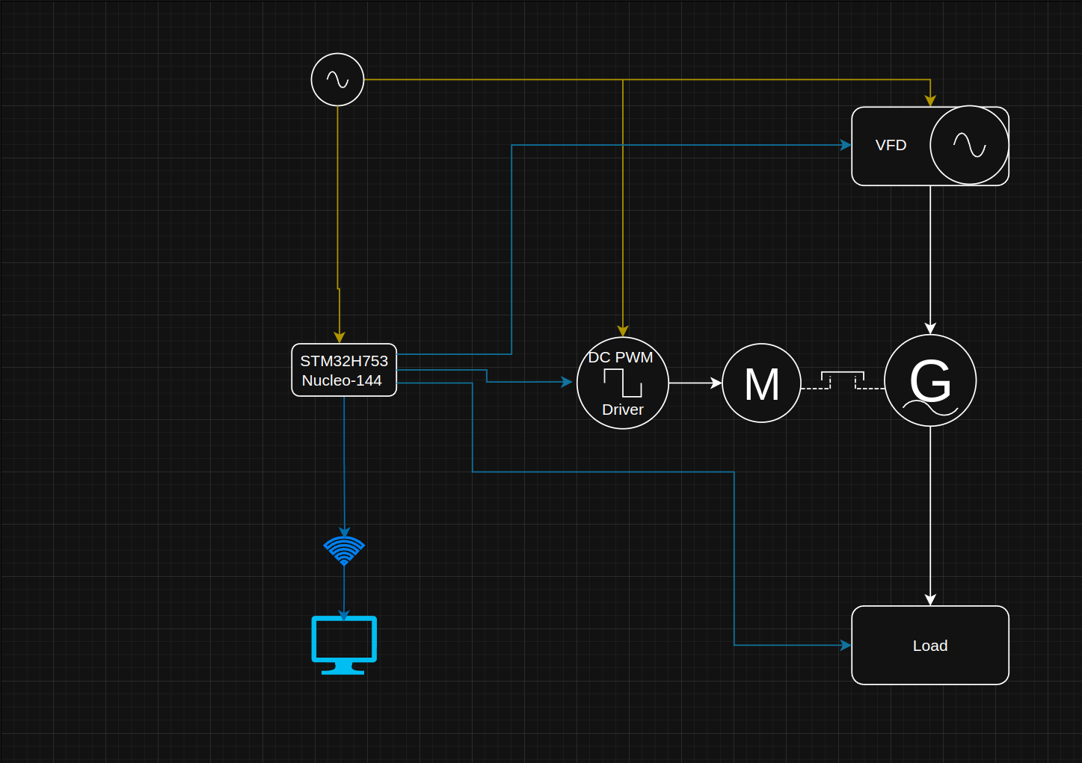
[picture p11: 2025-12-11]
docs/10_architecture/pic-selected-250629-1955-48.png

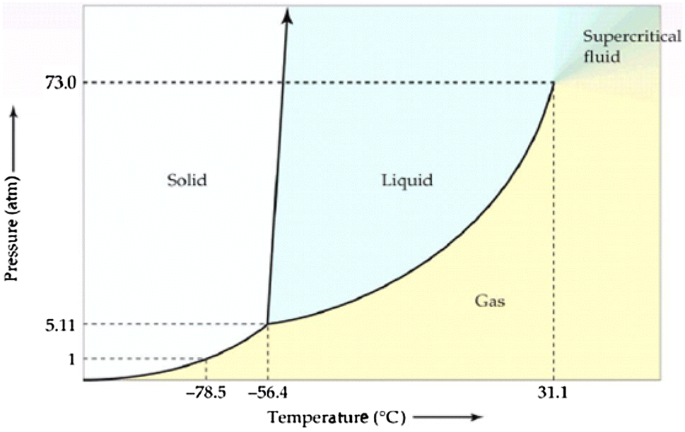
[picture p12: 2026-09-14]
githubMedia/waterPhaseGraph.png

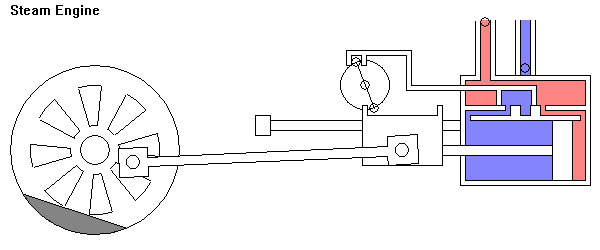
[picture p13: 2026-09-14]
githubMedia/dualActionSteamPistonEngine.gif

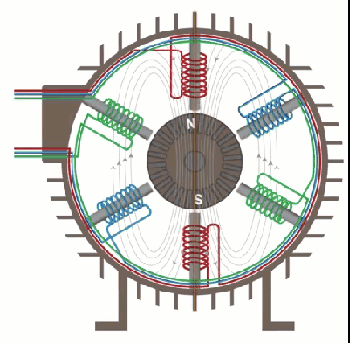
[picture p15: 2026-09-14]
githubMedia/3PhaseInductionMotorGraphic.gif

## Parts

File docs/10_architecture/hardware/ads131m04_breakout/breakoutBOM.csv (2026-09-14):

Reference | Qty | Value | DNP | Exclude from BOM | Exclude from Board | Exclude from Simulation | Exclude from Position Files | Footprint | Datasheet
C1 | 1 | 1nFC [0401|1005] | 0.01294 |  |  |  | ${EXCLUDE_FROM_POS_FILES} | Capacitor_SMD:C_0402_1005Metric
C2 | 1 | .1uF | 0.00622 |  |  |  | ${EXCLUDE_FROM_POS_FILES} | Capacitor_SMD:C_0201_0603Metric
C3 | 1 | 1uF | 0.11860 |  |  |  | ${EXCLUDE_FROM_POS_FILES} | Capacitor_SMD:C_0201_0603Metric
C4 | 1 | 220nF | 0.00874 |  |  |  | ${EXCLUDE_FROM_POS_FILES} | Capacitor_SMD:C_0402_1005Metric
J1 | 1 | Conn_01x19_Pin | 11.4 |  |  |  | ${EXCLUDE_FROM_POS_FILES} | Connector_PinHeader_2.54mm:PinHeader_1x10_P2.54mm_Vertical
R1 | 1 | 10k | 0.01305 |  |  |  | ${EXCLUDE_FROM_POS_FILES} | Resistor_SMD:R_0201_0603Metric | https://www.vishay.com/docs/20035/dcrcwe3.pdf
U1 | 1 | ADS131M04IPWR | 5.29 |  |  |  | ${EXCLUDE_FROM_POS_FILES} | Analog_DAC:PW20_TEX-L | https://www.ti.com/lit/gpn/ads131m04
Y1 | 1 | CB3LV-3I-8M192000 | 1.38 |  | 9.292 each board |  | ${EXCLUDE_FROM_POS_FILES} | Oscillator:OSC_CB3LV-3I-8M192000
 |  |  | 6.82081 | with pins = 18.22081 | w board wo pins = 16.11281 | board w pins = 27.51281

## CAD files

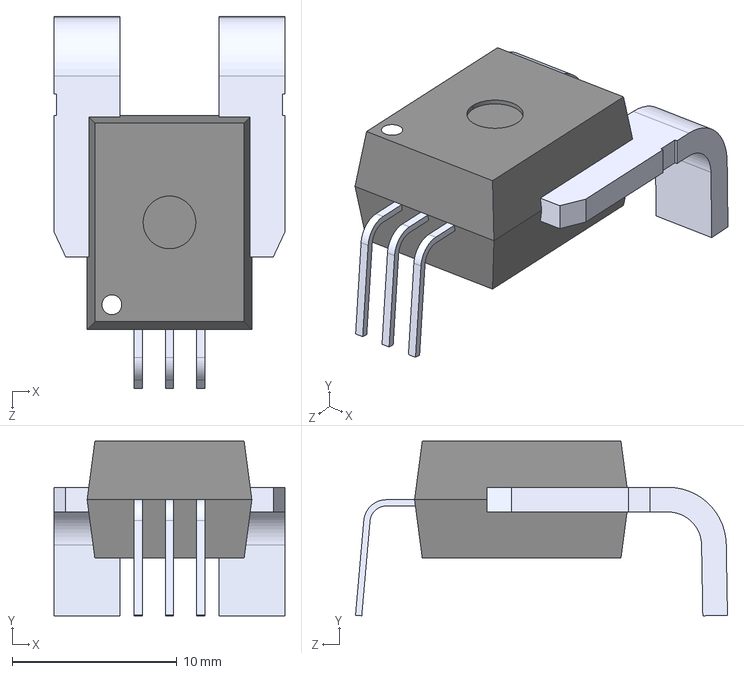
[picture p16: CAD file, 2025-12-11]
docs/50_motor_drive_data/ACS772/ACS772LCB-050B-PFF-T.step
14.0 x 10.6 x 22.6 mm

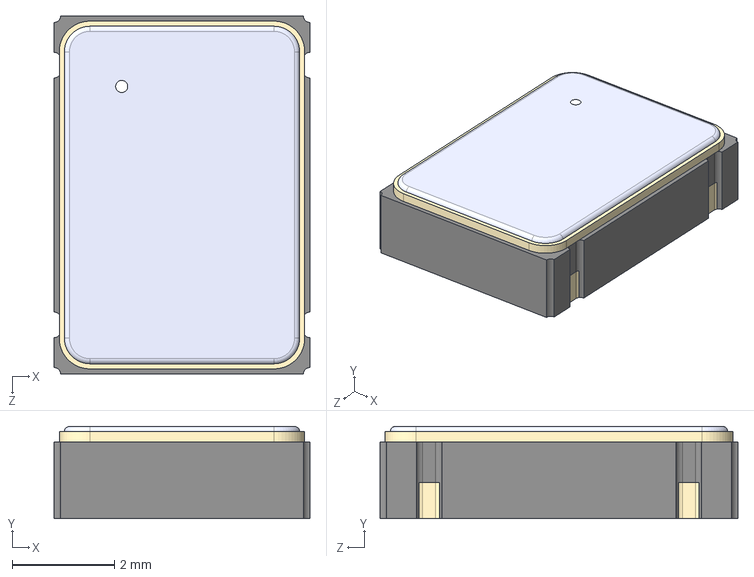
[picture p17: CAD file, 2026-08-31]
docs/50_motor_drive_data/ADS131M04/Breakout/CB3LV_3I_8M192000/CB3LV-3I-8M192000.step
5.00 x 1.80 x 7.00 mm

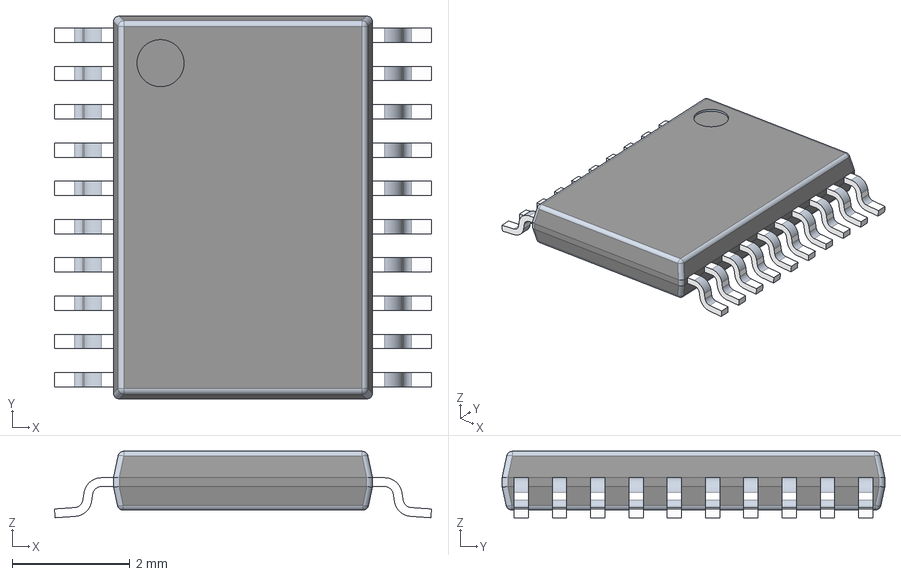
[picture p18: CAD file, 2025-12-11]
docs/50_motor_drive_data/ADS131M04/PW0020A.iges
6.40 x 6.50 x 1.13 mm

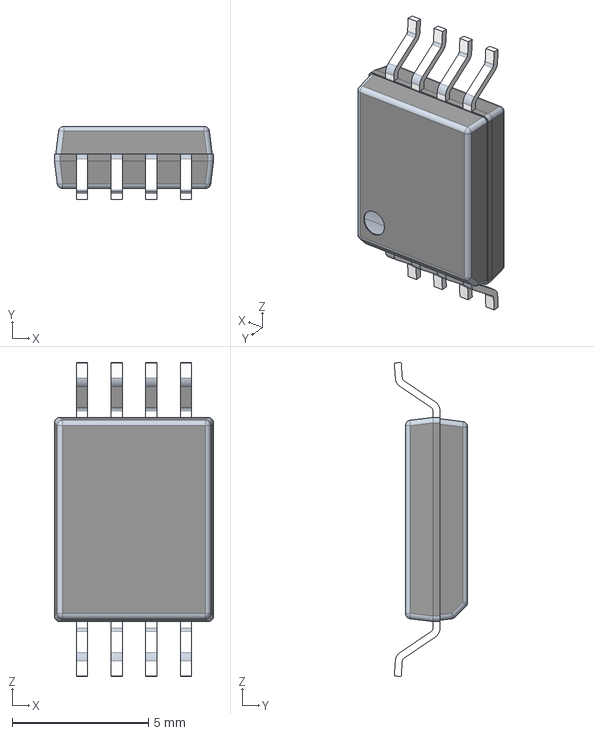
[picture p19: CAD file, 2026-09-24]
docs/50_motor_drive_data/AMC1302DWV/DWV0008A.iges
5.85 x 2.70 x 11.5 mm

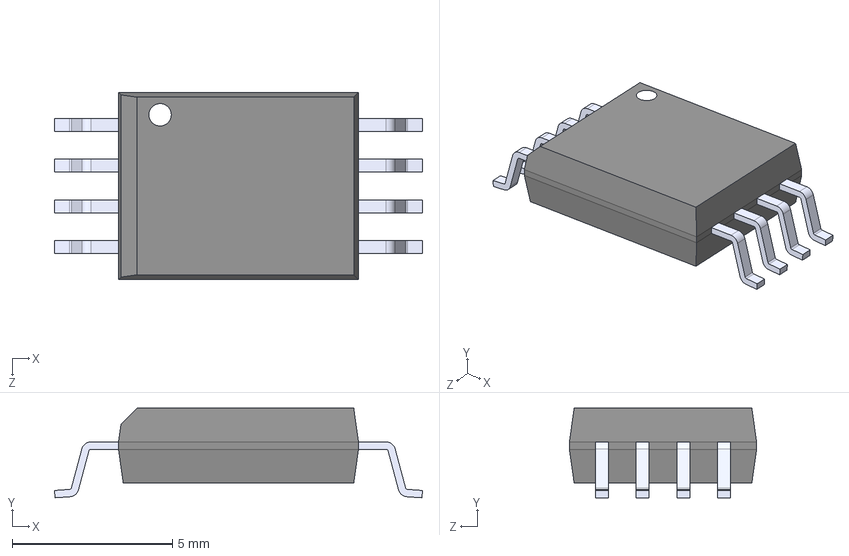
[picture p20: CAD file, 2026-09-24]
docs/50_motor_drive_data/amc1311/AMC1311BDWVR/AMC1311BDWVR.step
11.5 x 2.80 x 5.85 mm

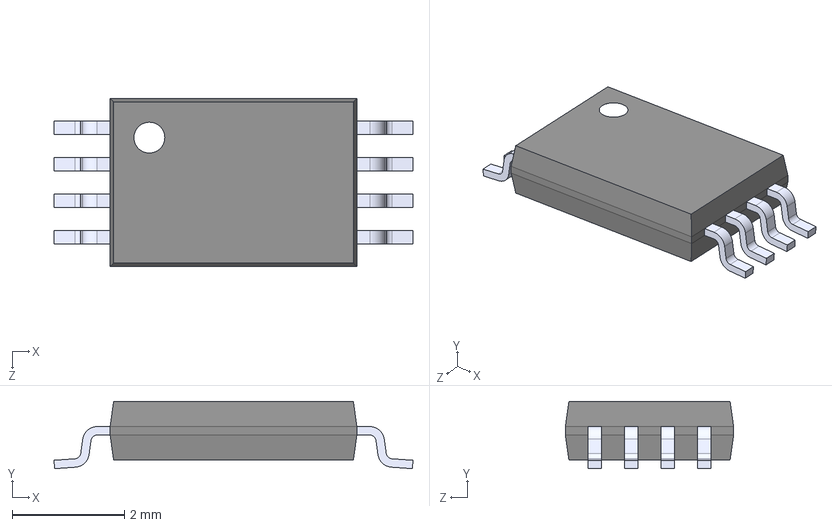
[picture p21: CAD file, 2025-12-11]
docs/50_motor_drive_data/INA240/INA240A1PWR.step
6.40 x 1.20 x 3.00 mm

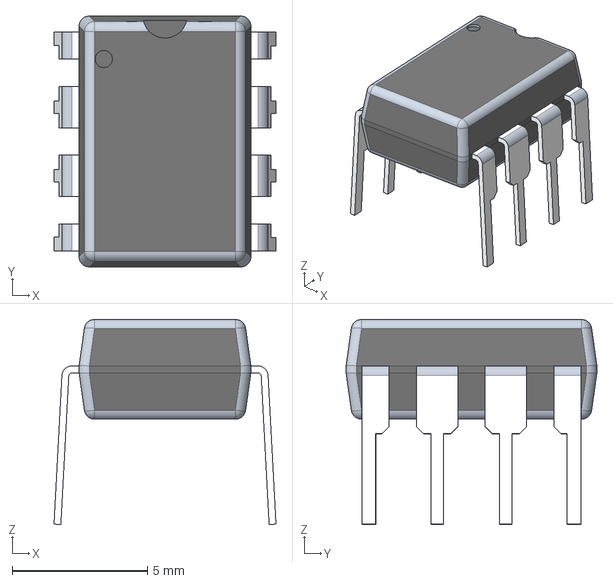
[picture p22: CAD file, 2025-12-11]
docs/50_motor_drive_data/RS-485_Transceiver_sn65hvd3082e/kicad 6+/P0008A.iges
8.20 x 9.27 x 7.58 mm

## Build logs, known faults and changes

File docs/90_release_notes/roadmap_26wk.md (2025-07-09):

# 26‑Week Project Road‑map  (Guv’nuh ‑ Embedded Governor Platform)

Each row shows what **must be delivered in the repo that week**, the core **topic to master**, the **standard(s)** that anchor the work, and **why a utility firmware team would care**.

| Wk | Deliverable → Git commit / video evidence | Study / Research Focus | Standards touched | Real‑world EMS relevance |
| -- | --- | --- | --- | --- |
| 1  | **System block diagram** PDF (docs/10\_architecture) | MCU clock tree • Isolation classes | IEC 60204‑1 colour codes | Clear system decomposition used in plant FAT docs |
| 2  | 24 V SMPS & Nucleo blinky on bench video | Brown‑out & boot pins | UL 489 breaker sizing | Basic power‑up checklist in any control cabinet |
| 3  | SPI‑DMA stream from ADS131M04 → CSV | Cache maintenance & ΣΔ decimation  | IEEE 1057 ADC terminology | High‑rate telemetry path like PMU recorders |
| 4  | README GIF – MATLAB step response (open‑loop PI) | Discrete PI design & Bode | ISA 5.5 symbols | PID tuning is bread‑and‑butter for hydro units |
| 5  | Hall CT + INA240 current capture demo | CMRR, shunt layout | IEEE 519 harmonic metrics | Grid codes demand current waveform analysis |
| 6  | **CI badge** – GitHub Actions build & unit tests | gcov coverage, Ceedling | — | Professional firmware workflow gate |
| 7  | RTIC state‑machine with overspeed **FAULT** | Safe‑state philosophy | IEC 61508 SIL‑2 | Mandatory for governor replacement projects |
| 8  | Modbus‑RTU master polling VFD (logic‑trace PNG) | Half‑duplex timing, CRC16 | ISA‑50 / Modbus | Legacy comms still dominant in TVA hydro plants |
| 9  | Closed‑loop PI on real VFD – bench video | Droop control, fixed‑point sat | IEEE 421.5 governor definitions | Mirrors Woodward hydro droop behaviour |
| 10 | **Zephyr sample PR merged** | Device‑tree overlays | Zephyr coding standard | OSS contribution signals peer‑reviewed code |
| 11 | InteractiveBOM HTML for sensor PCB | Component lifecycle, DNP lines | IPC‑2581 meta data | BOM clarity for procurement & spares |
| 12 | Sensor PCB v0.1 smoke test pass | Reflow profiles, QFN rework | J‑STD‑001 hand solder | Credible board bring‑up skill |
| 13 | Python smoke‑test script in `tests/01_smoke` | PySerial fixtures | IEEE 829 test docs | Automated regression like plant factory tests |
| 14 | Encoder RPM live over UART | Quadrature decoding, aliasing | IEC 60034 generator speed terms | Encoder feed is core to turbine trip logic |
| 15 | UART CLI for set‑point changes | CLI framing, SCPI vs custom | NERC MOD‑025 set‑point audit | Operator HMI hooks |
| 16 | Dump‑load PCB (Si8271 + MOSFET) routed | Kelvin routing, θJC | UL 1077 suppl. protect | Dump‑load equals resistor banks on wind/hydro |
| 17 | Wiring colour & fuse map (docs/30\_wiring) | NEC ampacity tables | NEC 310, EN 60204 | Field wiring doc for electricians |
| 18 | Dump‑load board assembled & heatsinked | Thermal compound, torque spec | IEC 60505 ageing | Reliability of high‑dissipation parts |
| 19 | Overspeed trip demo – logic analyser + video | Miller plateau, TVS clamp | IEC 61800‑5‑2 STO | Safety case evidence for turbine overspeed |
| 20 | Adaptive droop branch merged | Gain scheduling, anti‑windup | IEEE 421.2 dynamics | Maintains stability across load steps |
| 21 | React/Next.js dashboard (ESP32 Wi‑Fi) | WebSocket, CORS | ISA 101 HMI | Shows full‑stack SCADA interface capability |
| 22 | MISRA / Cppcheck report ≤10 warn | Static analysis deviations | MISRA C:2012 | Compliance ticks HR checklists |
| 23 | Doxygen GitHub Pages live | API grouping | IEEE Std‑2001 doc | In‑house firmware docs for maintenance |
| 24 | **EEI MASS/POSS test pass** PDF | Aptitude prep | EEI plant testing req | TVA prerequisite satisfied |
| 25 | 2‑min polished YouTube demo | Storyboard, audio mix | — | Marketing portfolio to recruiters |

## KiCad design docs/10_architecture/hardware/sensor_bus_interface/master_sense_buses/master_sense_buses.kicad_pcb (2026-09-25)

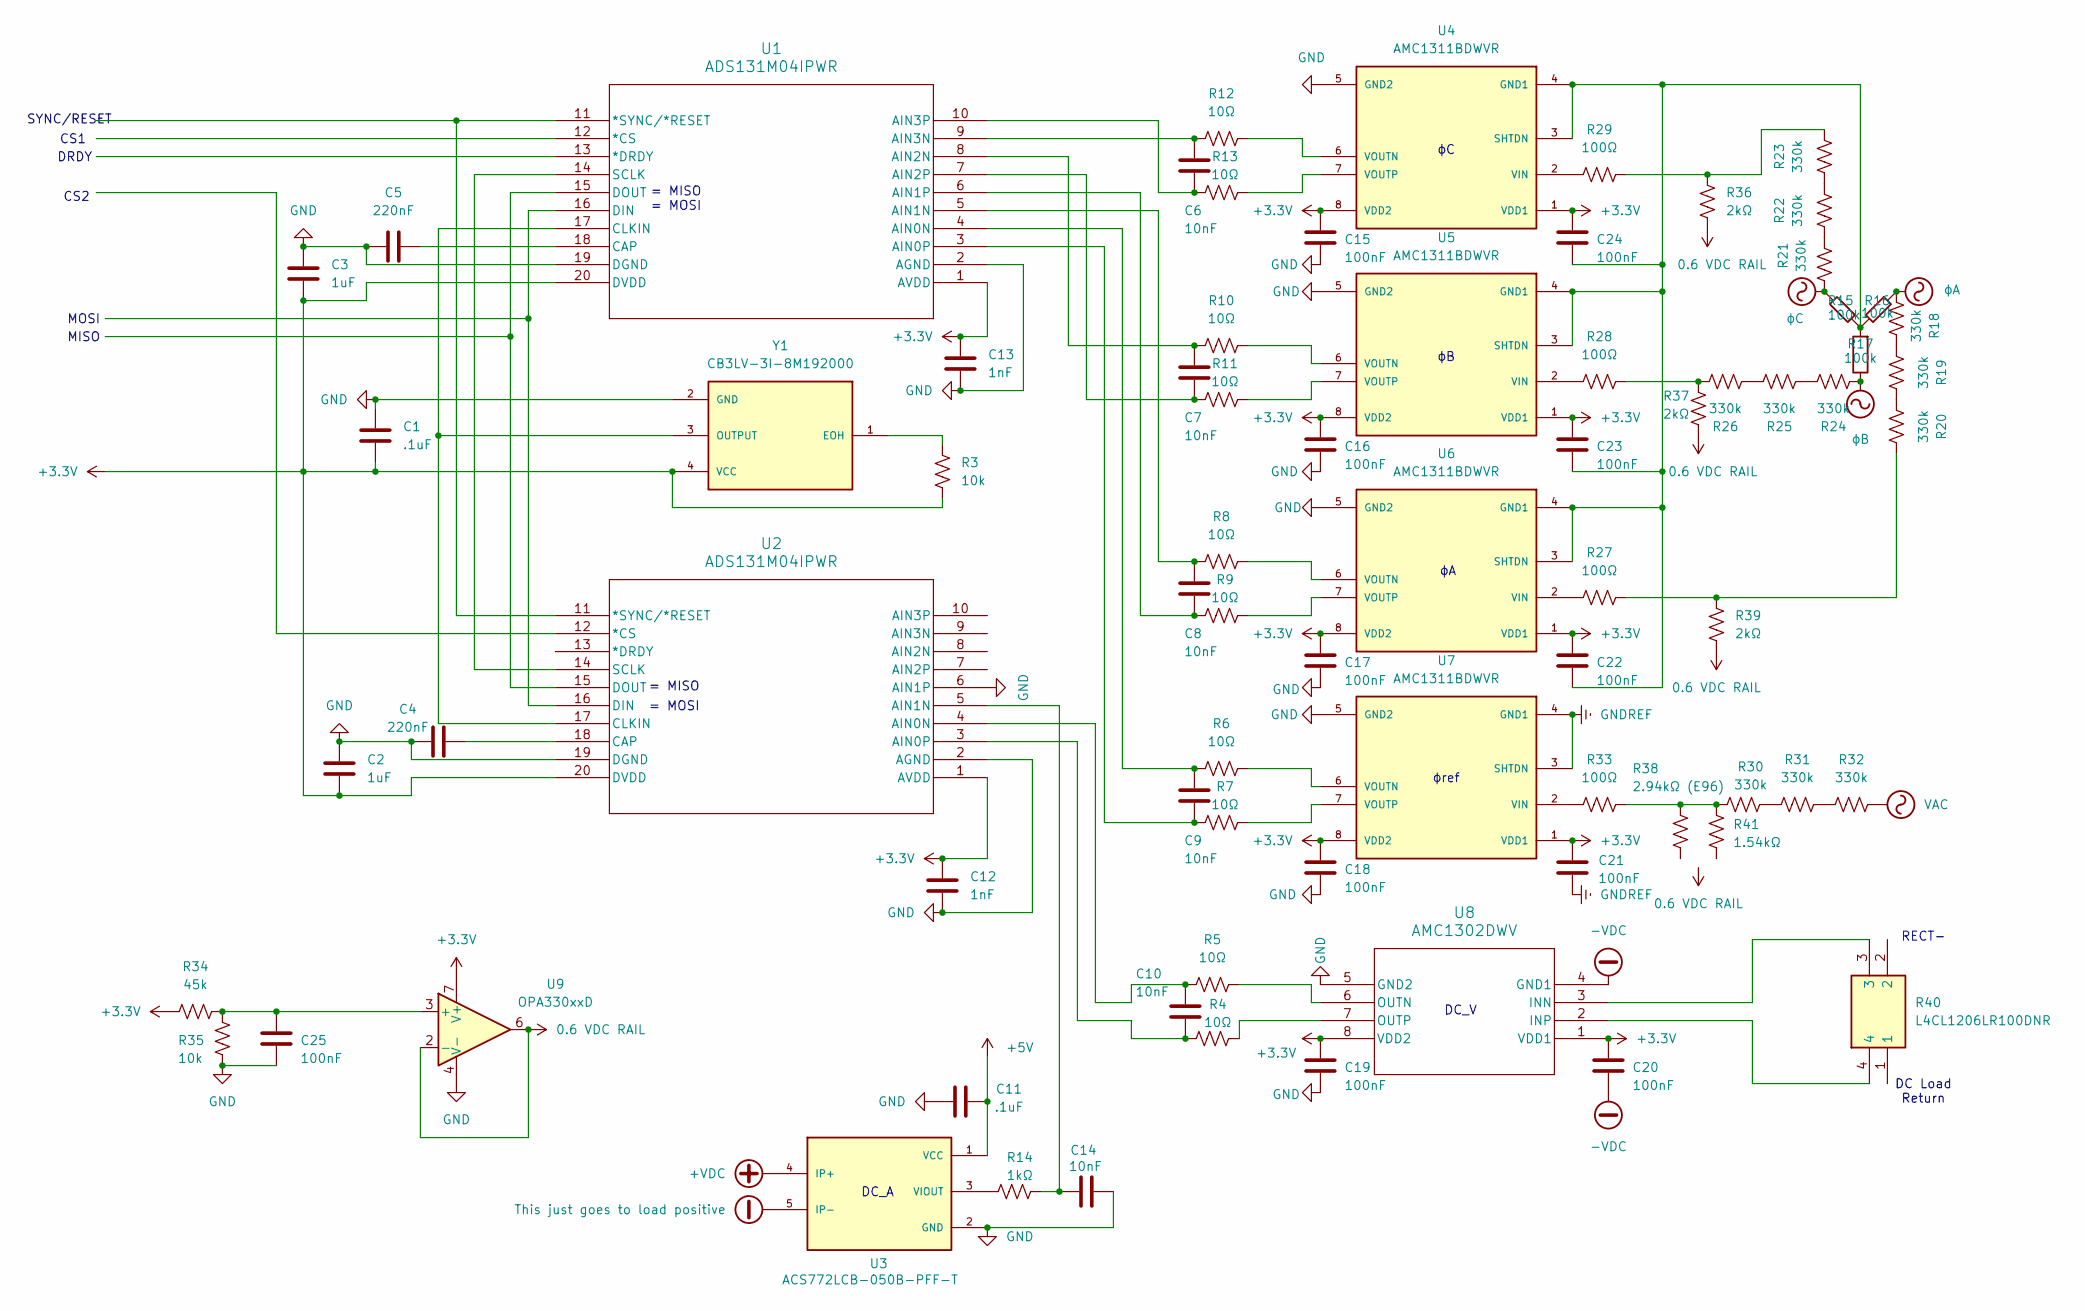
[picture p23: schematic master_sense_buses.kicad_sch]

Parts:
C1, C11: .1uF; C_0201_0603Metric
C2, C3: 1uF; C_0201_0603Metric
C4, C5: 220nF; C_0201_0603Metric
C6, C7, C8, C9, C10, C14: 10nF; C_0603_1608Metric
C12, C13: 1nF; C_0201_0603Metric
C15, C16, C17, C18, C19, C20, C21, C22, C23, C24, C25: 100nF; C_0201_0603Metric
R3: 10k; R_0603_1608Metric
R4, R5, R6, R7, R8, R9, R10, R11, R12, R13: 10Ω; R_0603_1608Metric
R14: 1kΩ; R_0603_1608Metric
R15, R16, R17: 100k; R_Axial_DIN0414_L11.9mm_D4.5mm_P15.24mm_Horizontal
R18, R19, R20, R21, R22, R23, R24, R25, R26, R30, R31, R32: 330k; R_1206_3216Metric
R27, R28, R29, R33: 100Ω; R_0805_2012Metric
R34: 45k; R_0603_1608Metric
R35: 10k; R_0201_0603Metric
R36, R37, R39: 2kΩ; R_1206_3216Metric
R38: 2.94kΩ (E96); R_1206_3216Metric
R40: L4CL1206LR100DNR; Mouser Part Number 576-L4CL1206LR100DNR
R41: 1.54kΩ; R_1206_3216Metric
U1, U2: ADS131M04IPWR; PW20_TEX-L
U3: ACS772LCB-050B-PFF-T; XDCR_ACS772LCB-050B-PFF-T; PARTREV 21
U4, U5, U6, U7: AMC1311BDWVR; SOIC127P1150X280-8N; PARTREV A
U8: AMC1302DWV; SOIC8_DMV_TEX-L
U9: OPA330xxD; SOIC-8_3.9x4.9mm_P1.27mm
Y1: CB3LV-3I-8M192000; OSC_CB3LV-3I-8M192000; PARTREV NA

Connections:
0.6 VDC RAIL: R36.2, R37.2, R39.2, U9.2 (-), U9.6
+3.3V: C1.2, C2.2, C3.2, C12.1, C13.1, C15.1, C16.1, C17.1, C18.1, C19.1, C20.1, C21.1, C22.1, C23.1, C24.1, R3.2, R34.2, U1.1 (AVDD), U1.20 (DVDD), U2.1 (AVDD), U2.20 (DVDD), U4.1 (VDD1), U4.8 (VDD2), U5.1 (VDD1), U5.8 (VDD2), U6.1 (VDD1), U6.8 (VDD2), U7.1 (VDD1), U7.8 (VDD2), U8.1 (VDD1), U8.8 (VDD2), U9.7 (V+), Y1.4 (VCC)
+5V: C11.2, U3.1 (VCC)
+VDC: U3.4 (IP+)
-VDC: C20.2, U8.4 (GND1)
GND: C1.1, C2.1, C3.1, C4.2, C5.1, C11.1, C12.2, C13.2, C14.2, C15.2, C16.2, C17.2, C18.2, C19.2, C25.2, R35.2, U1.2 (AGND), U1.19 (DGND), U2.2 (AGND), U2.6 (AIN1P), U2.19 (DGND), U3.2 (GND), U4.5 (GND2), U5.5 (GND2), U6.5 (GND2), U7.5 (GND2), U8.5 (GND2), U9.4 (V-), Y1.2 (GND)
GNDREF: C21.2, U7.3 (SHTDN), U7.4 (GND1)
unnamed: R18.1, R19.2
unnamed: R19.1, R20.2
unnamed: R20.1, R27.1, R39.1
unnamed: R21.1, R22.2
unnamed: R22.1, R23.2
unnamed: R23.1, R29.1, R36.1
unnamed: R24.1, R25.2
unnamed: R25.1, R26.2
unnamed: R26.1, R28.1, R37.1
unnamed: R30.1, R31.2
unnamed: R30.2, R33.1, R38.1, R41.1
unnamed: R31.1, R32.2
unnamed: U1.11 (*SYNC/*RESET), U2.11 (*SYNC/*RESET)
unnamed: C9.1, R6.2, U1.4 (AIN0N)
unnamed: C9.2, R7.2, U1.3 (AIN0P)
unnamed: C8.1, R8.2, U1.5 (AIN1N)
unnamed: C8.2, R9.2, U1.6 (AIN1P)
unnamed: C7.1, R10.2, U1.8 (AIN2N)
unnamed: C7.2, R11.2, U1.7 (AIN2P)
unnamed: C6.1, R12.2, U1.9 (AIN3N)
unnamed: C6.2, R13.2, U1.10 (AIN3P)
unnamed: C5.2, U1.18 (CAP)
unnamed: U1.17 (CLKIN), U2.17 (CLKIN), Y1.3 (OUTPUT)
unnamed: U1.16 (DIN), U2.16 (DIN)
unnamed: U1.15 (DOUT), U2.15 (DOUT)
unnamed: U1.14 (SCLK), U2.14 (SCLK)
unnamed: C10.1, R5.2, U2.4 (AIN0N)
unnamed: C10.2, R4.2, U2.3 (AIN0P)
unnamed: C14.1, R14.1, U2.5 (AIN1N)
unnamed: C4.1, U2.18 (CAP)
unnamed: R14.2, U3.3 (VIOUT)
unnamed: C22.2, C23.2, C24.2, R15.1, R16.2, R17.2, U4.3 (SHTDN), U4.4 (GND1), U5.3 (SHTDN), U5.4 (GND1), U6.3 (SHTDN), U6.4 (GND1)
unnamed: R29.2, U4.2 (VIN)
unnamed: R12.1, U4.6 (VOUTN)
unnamed: R13.1, U4.7 (VOUTP)
unnamed: R28.2, U5.2 (VIN)
unnamed: R10.1, U5.6 (VOUTN)
unnamed: R11.1, U5.7 (VOUTP)
unnamed: R27.2, U6.2 (VIN)
unnamed: R8.1, U6.6 (VOUTN)
unnamed: R9.1, U6.7 (VOUTP)
unnamed: R33.2, U7.2 (VIN)
unnamed: R6.1, U7.6 (VOUTN)
unnamed: R7.1, U7.7 (VOUTP)
unnamed: R40.3, U8.3 (INN)
unnamed: R40.4, U8.2 (INP)
unnamed: R5.1, U8.6 (OUTN)
unnamed: R4.1, U8.7 (OUTP)
unnamed: C25.1, R34.1, R35.1, U9.3 (+)
unnamed: R3.1, Y1.1 (EOH)
This just goes to load positive: U3.5 (IP-)
VAC: R32.1; also elsewhere on the board
ϕA: R16.1, R18.2
ϕB: R17.1, R24.2
ϕC: R15.2, R21.2

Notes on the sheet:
DC_A
DC Load Return
= MISO
= MOSI
RECT-
MOSI
DC_V
DRDY
CS2
ϕref
MISO
CS1
SYNC/RESET

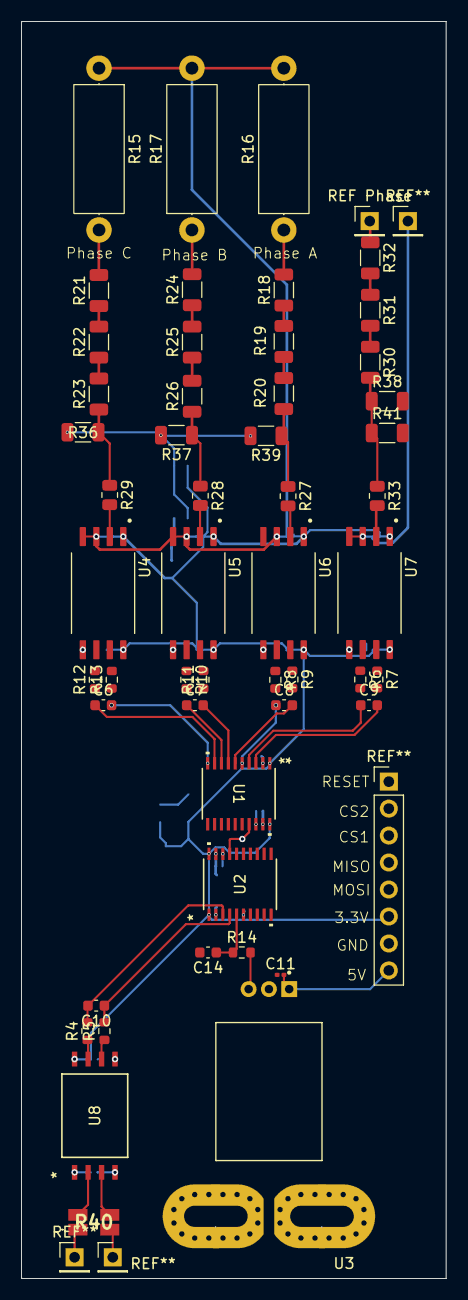
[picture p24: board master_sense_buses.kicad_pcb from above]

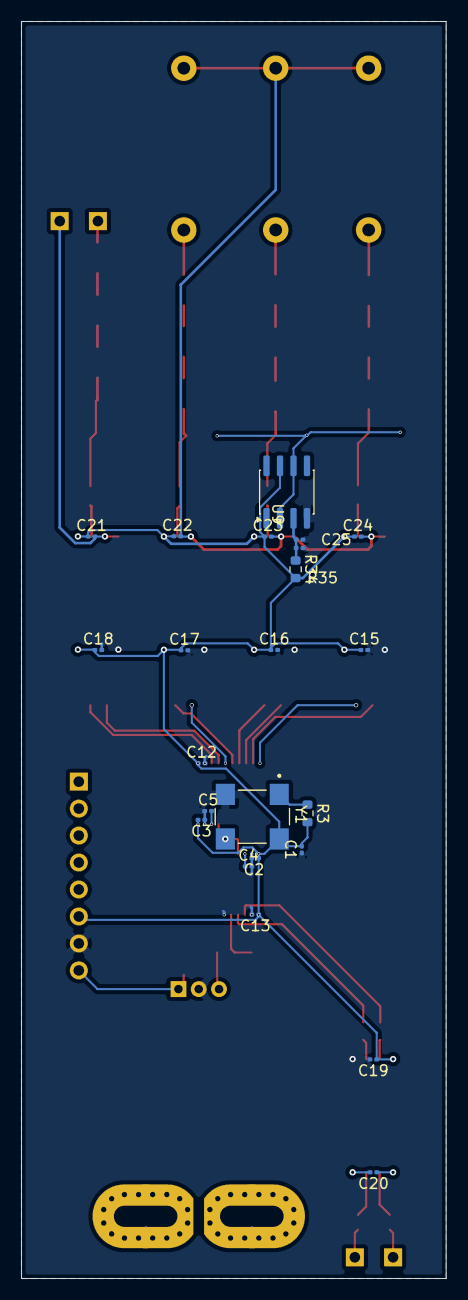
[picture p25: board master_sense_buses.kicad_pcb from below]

Board: 2 copper layers, 40.0 x 118.4 mm, 75 parts (23 on the bottom side), 60 nets.

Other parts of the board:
REF Phase: PinHeader_1x01_P2.54mm_Vertical

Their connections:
VAC: REF Phase.1; also elsewhere on the board

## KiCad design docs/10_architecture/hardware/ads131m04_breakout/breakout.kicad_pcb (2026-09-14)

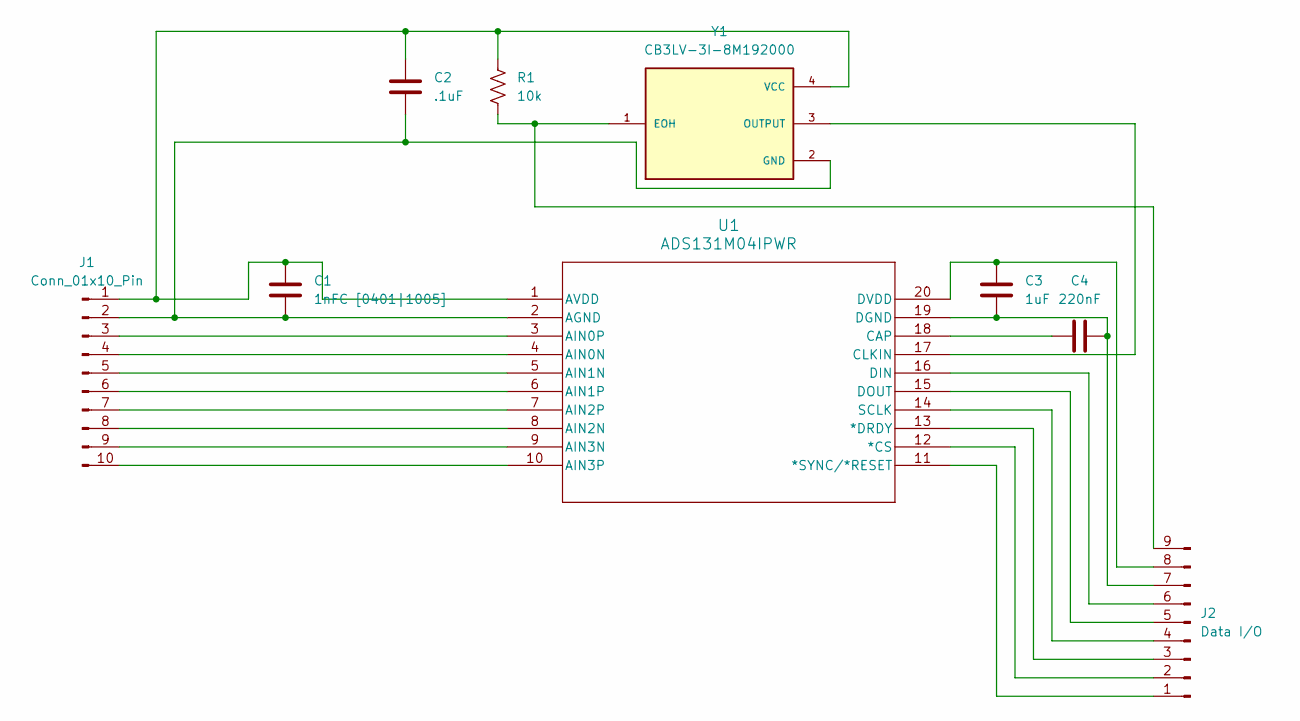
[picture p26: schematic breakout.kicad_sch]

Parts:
C1: 1nFC [0401|1005]; C_0402_1005Metric
C2: .1uF; C_0201_0603Metric
C3: 1uF; C_0201_0603Metric
C4: 220nF; C_0402_1005Metric
J1: Conn_01x10_Pin; PinHeader_1x10_P2.54mm_Vertical
J2: Data I/O; PinHeader_1x09_P2.54mm_Vertical
R1: 10k; R_0201_0603Metric
U1: ADS131M04IPWR; PW20_TEX-L
Y1: CB3LV-3I-8M192000; OSC_CB3LV-3I-8M192000; PARTREV NA

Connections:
unnamed: C1.1, C2.1, J1.1, R1.1, U1.1 (AVDD), Y1.4 (VCC)
unnamed: C1.2, C2.2, J1.2, U1.2 (AGND), Y1.2 (GND)
unnamed: J1.3, U1.3 (AIN0P)
unnamed: J1.4, U1.4 (AIN0N)
unnamed: J1.5, U1.5 (AIN1N)
unnamed: J1.6, U1.6 (AIN1P)
unnamed: J1.7, U1.7 (AIN2P)
unnamed: J1.8, U1.8 (AIN2N)
unnamed: J1.9, U1.9 (AIN3N)
unnamed: J1.10, U1.10 (AIN3P)
unnamed: J2.1, U1.11 (*SYNC/*RESET)
unnamed: J2.2, U1.12 (*CS)
unnamed: J2.3, U1.13 (*DRDY)
unnamed: J2.4, U1.14 (SCLK)
unnamed: J2.5, U1.15 (DOUT)
unnamed: J2.6, U1.16 (DIN)
unnamed: C3.2, C4.2, J2.7, U1.19 (DGND)
unnamed: C3.1, J2.8, U1.20 (DVDD)
unnamed: J2.9, R1.2, Y1.1 (EOH)
unnamed: C4.1, U1.18 (CAP)
unnamed: U1.17 (CLKIN), Y1.3 (OUTPUT)

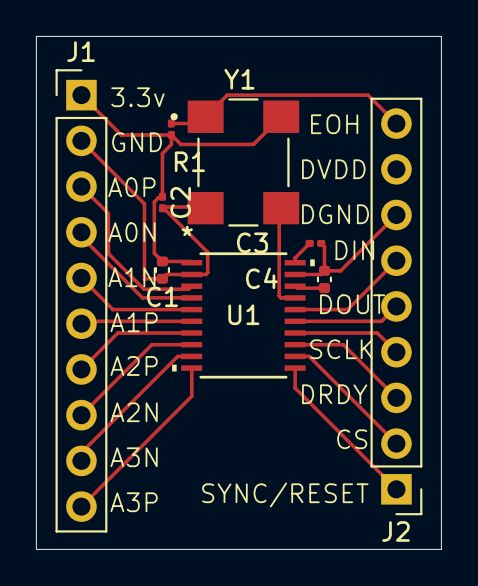
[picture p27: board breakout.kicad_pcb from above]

Board: 2 copper layers, 22.5 x 28.5 mm, 9 parts (0 on the bottom side), 21 nets.

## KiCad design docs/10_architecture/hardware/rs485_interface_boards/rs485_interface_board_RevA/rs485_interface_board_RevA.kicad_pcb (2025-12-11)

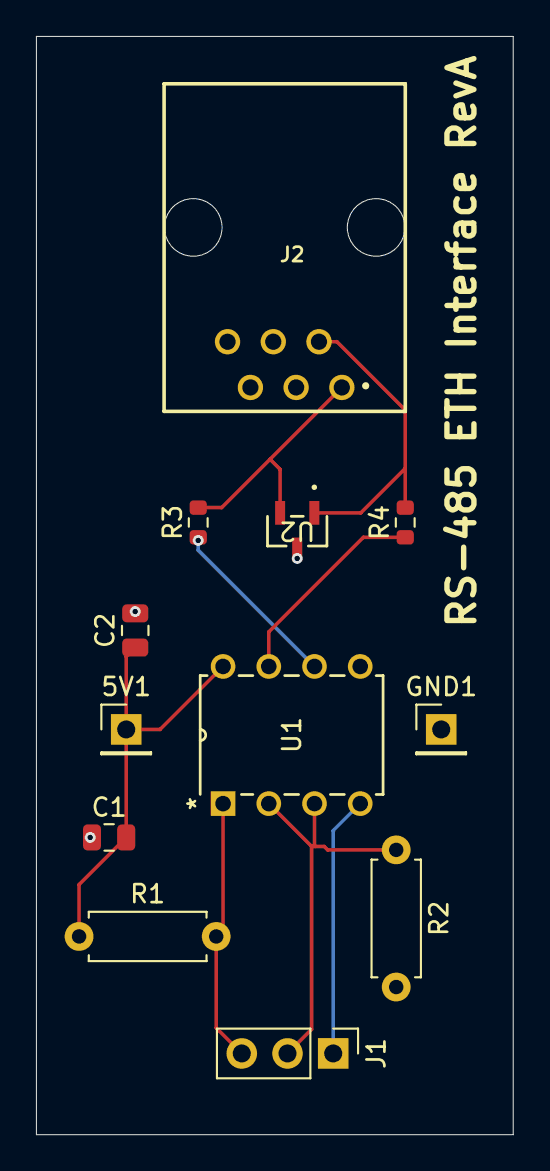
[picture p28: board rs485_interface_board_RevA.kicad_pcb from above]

Board: 2 copper layers, 26.5 x 61.0 mm, 12 parts (0 on the bottom side), 9 nets.

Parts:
5V1: Conn_01x01; PinHeader_1x01_P2.54mm_Vertical
C1, C2: 100 nf; C_0805_2012Metric
GND1: Conn_01x01; PinHeader_1x01_P2.54mm_Vertical
J1: Conn_01x03; PinHeader_1x03_P2.54mm_Vertical
J2: 615006141121
R1, R2: 10k; R_Axial_DIN0207_L6.3mm_D2.5mm_P7.62mm_Horizontal
R3, R4: 10 Ohm; R_0603_1608Metric
U1: SN65HVD3082EP; sn65hvd3082
U2: SM712.TCT; SOT23_SEM

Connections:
+5V: 5V1.1, C1.2, C2.1, R1.1, U1.8 (VCC)
GND: C1.1, C2.2, GND1.1, J2.3, R2.2, U1.5 (GND), U2.3
unnamed: J1.1, U1.4 (D)
unnamed: J1.2, R2.1, U1.2 (*RE), U1.3 (DE)
unnamed: J1.3, R1.2, U1.1 (R)
unnamed: J2.1, R3.2, U2.2
unnamed: J2.2, R4.2, U2.1
unnamed: R3.1, U1.6 (A)
unnamed: R4.1, U1.7 (B)

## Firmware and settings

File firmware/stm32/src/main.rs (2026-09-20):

// SPDX-License-Identifier: MIT OR Apache-2.0
#![no_std]
#![no_main]

defmt::timestamp!("{=u64:us}", { 0 });

use core::fmt::Write;
use defmt_rtt as _;
use panic_probe as _;

use rtic::app;
use rtic_monotonics::fugit::ExtU32;
use rtic_monotonics::systick::prelude::*;
use stm32h7xx_hal::{
    device::{TIM1, TIM2},
    gpio::{self, ExtiPin, GpioExt, Input, Output, PushPull},
    prelude::*,
    pwm,
    qei::Qei,
};

use cortex_m::peripheral::scb::SystemHandler;
use cortex_m::peripheral::{DCB, DWT};

mod guv;
mod models;

use crate::guv::prime_mover::PrimeMover;
use crate::guv::wcet::{CycleTimer, WcetTable};
use crate::models::{measurements::Measurements, status::WorkerStatus};
use nb::block;
use shared::models::state::states::{Fault, STATE};
use shared::models::telemetry::telemetry::{Command, LiveParam, PidGains, RunConfig, RunMode};
systick_monotonic!(Mono, 1_000);

/// Human-readable command name for defmt logging (Command doesn't derive defmt::Format).
fn cmd_name(c: &Command) -> &'static str {
    match c {
        Command::Ping => "Ping",
        Command::Configure(_) => "Configure",
        Command::Start => "Start",
        Command::Stop => "Stop",
        Command::EmergencyStop => "EmergencyStop",
        Command::LiveAdjust(_) => "LiveAdjust",
        Command::Set(_) => "Set",
        Command::ClearFaults => "ClearFaults",
        Command::Hello => "Hello",
        Command::HelloAck => "HelloAck",
        Command::SetLoad(_) => "SetLoad",
        Command::StepLoadUp => "StepLoadUp",
        Command::StepLoadDown => "StepLoadDown",
        Command::LoadProfile(_) => "LoadProfile",
        Command::SetAlignPhase(_) => "SetAlignPhase",
    }
}

/// Map a STATE to a stable table index for WCET tracking. Order must be stable
/// (append new states at the end) so banked numbers stay comparable.
fn state_index(s: STATE) -> usize {
    match s {
        STATE::BOOT => 0,
        STATE::CALIBRATE => 1,
        STATE::IDLE => 2,
        STATE::CONFIGURED => 3,
        STATE::SPOOLUP => 4,
        STATE::EXCITE => 5,
        STATE::PLL_LOCK => 6,
        STATE::READY => 7,
        STATE::GENERATE => 8,
        STATE::LOAD_REJECTION => 9,
        STATE::RAMP_DOWN => 10,
        STATE::MANUAL => 11,
        STATE::FAULT => 12,
        STATE::ESTOP => 13,
    }
}

fn enable_cycle_counter(dcb: &mut DCB, dwt: &mut DWT) {
    dcb.enable_trace(); // DEMCR.TRCENA = 1 (required for DWT)
    dwt.enable_cycle_counter(); // DWT.CTRL.CYCCNTENA = 1
}

// ── Safety limits (compiled-in; the server may only TUNE within these bounds) ──

pub const LOAD_REJECT_DROP_A: f32 = 2.0; // A drop in DC-bus current between 500Hz ticks = rejection
pub const LOAD_REJECT_MIN_A: f32 = 1.0; // only arm the detector above this DC-bus current
pub const DC_OVERVOLT_LIMIT: f32 = 300.0; // V — DC bus ceiling (tune to your rectifier)
pub const DC_OVERCURRENT_LIMIT: f32 = 20.0; // A — DC bus current ceiling
/// Active from boot with zero config — the autonomous-mode ceiling.
pub const OVERSPEED_LIMIT_DEFAULT: f32 = 2800.0;
/// Absolute bounds any server-commanded limit is clamped to. The server can
/// never disable protection nor set an instant-trip value.
pub const OVERSPEED_LIMIT_MIN: f32 = 500.0;
pub const OVERSPEED_LIMIT_MAX: f32 = 3000.0; // ← true mechanical never-exceed
/// RPM readings outside this window (or non-finite) mean the sensor is lying.
pub const RPM_PLAUSIBLE_MAX: f32 = 4000.0;

// ── Deadline monitoring (execution-time budget per control iteration) ──

/// The control loop period in cycles. At SYSCLK_HZ and 100 Hz (10 ms):
///   64_000_000 / 100 = 640_000 cycles per 10 ms period.
/// Keep in sync with the loop rate (dt_ms) and SYSCLK.
pub const CONTROL_PERIOD_CYCLES: u32 = crate::guv::wcet::SYSCLK_HZ / 100;

/// Fraction of the period a state's execution may occupy before it counts as an
/// overrun. 0.8 = 80% — loose enough that only genuine degradation trips (the
/// loop normally runs at single-digit % utilization), leaving headroom for the
/// priority-2 supervisor preemption + the UART ISR + jitter. Tighten for more
/// sensitivity.
pub const DEADLINE_BUDGET_FRAC: f32 = 0.8;

/// The per-iteration cycle budget, derived. Execution above this = one overrun.
pub const DEADLINE_BUDGET_CYCLES: u32 =
    (CONTROL_PERIOD_CYCLES as f32 * DEADLINE_BUDGET_FRAC) as u32;

/// How many CONSECUTIVE overruns in a deadline-bearing state before tripping.
/// 3 = ~30 ms of sustained overrun — a real degradation, not a one-off blip
/// (cold-cache first-hit, a single scheduling hiccup). Prevents nuisance trips.
pub const DEADLINE_MISS_STREAK: u32 = 3;

/// Whether a state is time-critical enough to enforce an execution-time
/// deadline. Active-control states have hard timing requirements; BOOT / IDLE /
/// CONFIGURED / FAULT / ESTOP do not (a slow IDLE tick endangers nothing).
fn state_has_deadline(s: STATE) -> bool {
    matches!(
        s,
        STATE::SPOOLUP
            | STATE::EXCITE
            | STATE::PLL_LOCK
            | STATE::READY
            | STATE::GENERATE
            | STATE::LOAD_REJECTION
            | STATE::RAMP_DOWN
            | STATE::CALIBRATE
            | STATE::MANUAL
    )
}

/// Clamp a server-commanded overspeed limit into the safe envelope.
#[inline]
pub fn clamp_overspeed_limit(requested: f32) -> f32 {
    if !requested.is_finite() {
        return OVERSPEED_LIMIT_DEFAULT;
    }
    requested.clamp(OVERSPEED_LIMIT_MIN, OVERSPEED_LIMIT_MAX)
}

#[app(device = stm32h7xx_hal::pac, dispatchers = [EXTI0, EXTI1, EXTI2])]
mod app {
    use super::*;
    use shared::models::telemetry::telemetry::{Uplink, DEFAULT_PROFILE};
    use stm32h7xx_hal::qei::Qei;
    type Motor = crate::guv::motor::MotorController;
    type Cfg = Option<RunConfig>;

    #[shared]
    pub struct Shared {
        // GPIO
        ld1: gpio::Pin<'B', 0, Output<PushPull>>,  // green
        ld2: gpio::Pin<'E', 1, Output<PushPull>>,  // yellow
        ld3: gpio::Pin<'B', 14, Output<PushPull>>, // red
        relay: gpio::Pin<'E', 0, Output<PushPull>>,

        // Motor (wraps inverted PWM logic)
        motor: crate::guv::motor::MotorController,

        // Encoder
        encoder: Qei<TIM2>,

        // UART to ESP32
        tx: stm32h7xx_hal::serial::Tx<stm32h7xx_hal::pac::UART4>,
        rx: stm32h7xx_hal::serial::Rx<stm32h7xx_hal::pac::UART4>,

        //load
        load_bank: crate::guv::load_bank::LoadBank,

        adc: crate::guv::adc::Ads131Pair,
        adc_acc: crate::guv::adc::Accumulator,
        adc_meas: crate::guv::adc::Measurements,

        // State
        pub state: STATE,
        pub run_config: Option<RunConfig>,
        pub current_rpm: f32,
        pub last_fault: Option<Fault>,
        pub cmd_in: heapless::Deque<Command, 8>,
        pub align_target: crate::guv::adc::AlignPhase,
        pub measurements: crate::models::measurements::Measurements,

        pub calibration: Option<crate::guv::calibrate::CalResult>,
        pub pending_report: Option<shared::models::telemetry::telemetry::CalibrationReport>,

        /// Overspeed trip ceiling. Boots at the compiled default so protection
        /// is active with zero config; the command path may later set it (clamped).
        /// Comms loss never removes it — the local supervisor keeps enforcing it.
        pub overspeed_limit: f32,

        /// Active setpoint profile, if one is loaded. None = use static
        /// target_rpm (backward compatible) OR the compiled DEFAULT_PROFILE for
        /// a profile run — see the control-loop integration below.
        pub active_profile: Option<shared::models::telemetry::telemetry::SetpointProfile>,

        pub wcet: WcetTable,
    }

    #[local]
    pub struct Local {
        safety_init_done: bool,
        cmd_buf: [u8; 128], // owned by the UART4 ISR
        cmd_len: usize,
        pid: crate::guv::pid::PidController,
        ramp: Option<crate::guv::ramp::Ramp>,
        run_elapsed_ms: u32,
        calibrator: Option<crate::guv::calibrate::Calibrator>,
        boot_hello_attempts: u32,
        adc_drdy: crate::guv::adc::Drdy,
        last_p_total: f32,
        estop: gpio::Pin<'E', 6, Input>,
    }

    #[init]
    fn init(mut cx: init::Context) -> (Shared, Local) {
        defmt::info!("System Boot: Initializing...");

        let mut board = crate::guv::states::boot::setup(cx.device);

        unsafe {
            cx.core.SCB.set_priority(SystemHandler::SysTick, 255);
        }

        // Wrap PWM in MotorController — constructor forces motor off
        let motor = crate::guv::motor::MotorController::new(board.motor_pwm);

        let sys_freq = board.clocks.sysclk().to_Hz();
        Mono::start(cx.core.SYST, sys_freq);
        defmt::info!("INIT: setup() returned");
        let adc = crate::guv::adc::Ads131Pair::new(
            board.adc_spi,
            board.adc_cs1,
            board.adc_cs2,
            board.adc_sync,
            board.adc_rst,
        );

        defmt::info!("INIT: Ads131Pair::new() complete");
        let load_bank = crate::guv::load_bank::LoadBank::new(board.load_step_1, board.load_step_2);
        state_manager::spawn().ok();
        telemetry_task::spawn().ok();
        safety_supervisor::spawn().ok();
        //for wcet calc
        cx.core.DCB.enable_trace();
        cx.core.DWT.enable_cycle_counter();
        board.ld3.set_high(); // Red = booting
        (
            Shared {
                state: STATE::BOOT,
                ld1: board.ld1,
                ld2: board.ld2,
                ld3: board.ld3,
                relay: board.motor_relay,
                motor,
                encoder: board.encoder,
                tx: board.tx,
                rx: board.rx,
                run_config: None,
                current_rpm: 0.0,
                last_fault: None,
                cmd_in: heapless::Deque::new(),
                calibration: None,
                pending_report: None,
                measurements: crate::models::measurements::Measurements::default(),
                overspeed_limit: crate::OVERSPEED_LIMIT_DEFAULT,
                active_profile: Some(DEFAULT_PROFILE),
                wcet: WcetTable::new(),
                load_bank,
                adc,
                adc_acc: crate::guv::adc::Accumulator::default(),
                adc_meas: crate::guv::adc::Measurements::default(),
                align_target: crate::guv::adc::AlignPhase::default(),
            },
            Local {
                safety_init_done: false,
                cmd_buf: [0u8; 128],
                cmd_len: 0,
                pid: crate::guv::pid::PidController::new(PidGains::default()),
                ramp: None,
                run_elapsed_ms: 0,
                calibrator: None,
                boot_hello_attempts: 0,
                last_p_total: 0.0,
                adc_drdy: board.adc_drdy,
                estop: board.estop,
            },
        )
    }
    // ────────────────────────────────────────────
    //  Safety Supervisor — independent, comms-agnostic, PREEMPTIVE
    //  Priority 2: preempts state_manager & telemetry (both pri 1). Runs at
    //  500 Hz — 5× the control loop — so overspeed is caught fast. Reads ONLY
    //  local sensors; no dependency on ESP32 or server. This layer keeps the
    //  machine safe even when everything upstream is dead.
    // ────────────────────────────────────────────
    #[task(priority = 2,
        shared = [current_rpm, overspeed_limit, motor, relay,
            state, last_fault, ld3, ld2, ld1, adc_acc, load_bank] ,
        local = [last_p_total,estop])]
    async fn safety_supervisor(mut cx: safety_supervisor::Context) {
        const SUPERVISE_MS: u32 = 2; // 500 Hz

        loop {
            Mono::delay(SUPERVISE_MS.millis()).await;

            // ── PHYSICAL E-STOP — highest priority, fail-safe ──
            // Pin HIGH = E-stop (button pressed OR wire broken). LOW = closed/running.
            let estop_active = cx.local.estop.is_high();

            if estop_active {
                // Kill everything immediately, every cycle it's held.
                cx.shared.motor.lock(|m| m.emergency_off());
                cx.shared.relay.lock(|r| r.set_low());
                cx.shared.load_bank.lock(|lb| lb.emergency_shed());

                // Transition to ESTOP on the edge (don't spam).
                let already_estopped = cx.shared.state.lock(|s| matches!(*s, STATE::ESTOP));
                if !already_estopped {
                    defmt::error!("!! PHYSICAL E-STOP ENGAGED !!");
                    cx.shared.state.lock(|s| *s = STATE::ESTOP);
                    cx.shared
                        .last_fault
                        .lock(|f| *f = Some(Fault::EmergencyStop));
                    cx.shared.ld3.lock(|l| l.set_high());
                    cx.shared.ld1.lock(|l| l.set_low());
                    cx.shared.ld2.lock(|l| l.set_low());
                }
                // Skip the rest of the supervisor while E-stopped — hold safe.
                continue;
            }

            let rpm = cx.shared.current_rpm.lock(|r| *r);
            let limit = cx.shared.overspeed_limit.lock(|l| *l);

            // ── evaluate LOCAL trip conditions (no comms involved) ──
            let trip: Option<Fault> = if !rpm.is_finite() || rpm.abs() > crate::RPM_PLAUSIBLE_MAX {
                Some(Fault::SensorOutOfRange)
            } else if rpm > limit {
                Some(Fault::Overspeed)
            } else {
                None
            };

            if let Some(fault) = trip {
                // Actuators OFF first — fastest path to safe.
                cx.shared.motor.lock(|m| m.emergency_off());
                cx.shared.relay.lock(|r| r.set_low());

                // Transition + log only on the EDGE (don't spam while coasting down).
                let already_faulted = cx
                    .shared
                    .state
                    .lock(|s| matches!(*s, STATE::FAULT | STATE::ESTOP));

                if !already_faulted {
                    cx.shared.last_fault.lock(|f| *f = Some(fault));
                    cx.shared.state.lock(|s| *s = STATE::FAULT);
                    cx.shared.ld3.lock(|l| l.set_high());

                    if rpm > limit && rpm.is_finite() {
                        defmt::error!(
                            "!! OVERSPEED TRIP !! rpm={} limit={}",
                            rpm as i32,
                            limit as i32
                        );
                    } else {
                        defmt::error!("!! SENSOR TRIP !! implausible rpm={}", rpm as i32);
                    }
                }
                // Keep forcing off every cycle while faulted — the supervisor
                // doesn't rely on state_manager running to hold safe.
            }
            // ── ADC-based fast protection (runs every 500Hz tick) ──
            let prot = cx
                .shared
                .adc_acc
                .lock(|acc| crate::guv::adc::finalize_protection(acc, 1.0));

            // LOAD REJECTION: a sudden DC-bus CURRENT drop → generator unloaded →
            // overspeed hazard (critical for a turbine). React LOCALLY, now.
            // (Power isn't computed on-device anymore; rectifier current is the
            //  load proxy — a big i_dc drop = load rejected. Same feedforward source.)
            let last_i = *cx.local.last_p_total; // repurposed: last DC-bus current (A)
            let i_drop = last_i - prot.i_dc;
            if last_i > crate::LOAD_REJECT_MIN_A && i_drop > crate::LOAD_REJECT_DROP_A {
                let already_faulted = cx
                    .shared
                    .state
                    .lock(|s| matches!(*s, STATE::FAULT | STATE::ESTOP));
                if !already_faulted {
                    defmt::warn!(
                        "!! LOAD REJECTION !! i_dc {}A -> {}A (drop {}A)",
                        last_i as i32,
                        prot.i_dc as i32,
                        i_drop as i32
                    );
                    // shed the bank immediately + go to fault.
                    cx.shared.load_bank.lock(|lb| lb.emergency_shed());
                    cx.shared.motor.lock(|m| m.emergency_off());
                    cx.shared.relay.lock(|r| r.set_low());
                    cx.shared
                        .last_fault
                        .lock(|f| *f = Some(Fault::LoadRejection));
                    cx.shared.state.lock(|s| *s = STATE::FAULT);
                    cx.shared.ld3.lock(|l| l.set_high());
                }
            }
            *cx.local.last_p_total = prot.i_dc;

            // fast DC-bus electrical trips (local, no comms):
            if prot.v_dc > crate::DC_OVERVOLT_LIMIT || prot.i_dc > crate::DC_OVERCURRENT_LIMIT {
                let already_faulted = cx
                    .shared
                    .state
                    .lock(|s| matches!(*s, STATE::FAULT | STATE::ESTOP));
                if !already_faulted {
                    defmt::error!(
                        "!! DC BUS TRIP !! v={} i={}",
                        prot.v_dc as i32,
                        prot.i_dc as i32
                    );
                    cx.shared.load_bank.lock(|lb| lb.emergency_shed());
                    cx.shared.motor.lock(|m| m.emergency_off());
                    cx.shared.relay.lock(|r| r.set_low());
                    cx.shared.last_fault.lock(|f| {
                        *f = Some(if prot.v_dc > crate::DC_OVERVOLT_LIMIT {
                            Fault::OverVoltage
                        } else {
                            Fault::OverCurrent
                        })
                    });
                    cx.shared.state.lock(|s| *s = STATE::FAULT);
                    cx.shared.ld3.lock(|l| l.set_high());
                }
            }
        }
    }
    // ────────────────────────────────────────────
    //  State Manager — the main control loop
    // ────────────────────────────────────────────
    #[task(priority = 1,
        shared = [state, ld1, ld2, ld3, relay, load_bank, motor, tx, rx, run_config,
            current_rpm, last_fault, cmd_in, calibration, pending_report, active_profile,
            wcet, adc_acc,adc_meas, align_target],
        local = [safety_init_done, pid, ramp, run_elapsed_ms, calibrator, boot_hello_attempts]
    )]
    async fn state_manager(mut cx: state_manager::Context) {
        let dt_ms: u32 = 10;

        loop {
            let current_state = cx.shared.state.lock(|s| *s);

            // ── Pull one decoded command from the ISR-fed queue ──
            let received_cmd: Option<Command> = cx.shared.cmd_in.lock(|q| q.pop_front());
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

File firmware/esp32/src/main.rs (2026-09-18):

#![no_std]
#![no_main]

/**
 * this will entail with the help of shared models and forethought of the data herein collected from the stm32
 *
 * insofar as the stm32 can manage to do so, I don't think it makes much sense to gather second hand information,
 * it may be prudent to develop the control loop so that within different priorities and where data is more crucial we can assign
 * differing or dynamic priorities in order to assert that the stm32 will remain in tolerance no matter what,
 * running efficiently and within spec is top priority of course but ensuring that esp32 is hydrated so we have ample resoultion of data
 * is crucial to developing the project further and in a clever manner.
 *
 * the esp32 will facilitate communications to and from the stm32 and the api server separately once recieved data,
 * which said server will store data for display to the masses
 * 		(and of course to our desktop application,
 * 			this application will be able to be deployed as a webclient via dioxus
 * 				with sub/prime collected data and more of a professional write up to show thought process, progress, and more importantly 67)
 */
extern crate alloc;

use embassy_executor::Spawner;
use embassy_net::{tcp::TcpSocket, IpListenEndpoint, Runner, Stack, StackResources};
use embassy_time::{Duration, Timer};
use embedded_io::Read;
use embedded_io::Write;
use embedded_io_async::Write as AsyncWrite;
use esp_backtrace as _;
use esp_hal::{
    clock::CpuClock,
    gpio::{Level, Output},
    rng::Rng,
    timer::timg::TimerGroup,
    uart::{Config, Uart},
};
use esp_println::println;
use esp_wifi::{
    init,
    wifi::{
        ClientConfiguration, Configuration, WifiController, WifiDevice, WifiEvent, WifiStaDevice,
        WifiState,
    },
    EspWifiController,
};
use shared::models::telemetry::telemetry::{Command, Uplink};

const SSID: &str = env!("WIFI_SSID");
const PASS: &str = env!("WIFI_PASS");
const PORT: u16 = {
    let s = env!("TCP_PORT").as_bytes();
    let mut val: u16 = 0;
    let mut i = 0;
    while i < s.len() {
        val = val * 10 + (s[i] - b'0') as u16;
        i += 1;
    }
    val
};

macro_rules! mk_static {
    ($t:ty,$val:expr) => {{
        static STATIC_CELL: static_cell::StaticCell<$t> = static_cell::StaticCell::new();
        let x = STATIC_CELL.uninit().write(($val));
        x
    }};
}

#[esp_hal_embassy::main]
async fn main(spawner: Spawner) -> ! {
    let config = esp_hal::Config::default().with_cpu_clock(CpuClock::max());
    let peripherals = esp_hal::init(config);

    esp_alloc::heap_allocator!(72 * 1024);

    let mut led = Output::new(peripherals.GPIO2, Level::Low);

    let uart_config = Config::default().with_baudrate(115200);
    let mut uart1 = Uart::new(peripherals.UART1, uart_config)
        .unwrap()
        .with_tx(peripherals.GPIO23)
        .with_rx(peripherals.GPIO22);

    println!("ESP32 Booted. Waiting for STM32 handshake...");

    // Announce our boot to the STM32 (framed). If the STM32 is already running,
    // it will HelloAck and re-sync. If the STM32 is also booting, it's sending
    // its own Hello which we answer in tcp_task.
    {
        use postcard::to_slice_cobs;
        let mut buf = [0u8; 16];
        if let Ok(enc) = to_slice_cobs(&Command::Hello, &mut buf) {
            uart1.write_all(enc).ok();
        }
    }
    println!("ESP32 booted — sent Hello to STM32");

    // --- WIFI INIT ---
    let timg0 = TimerGroup::new(peripherals.TIMG0);
    let mut rng = Rng::new(peripherals.RNG);

    let init = &*mk_static!(
        EspWifiController<'static>,
        init(timg0.timer0, rng.clone(), peripherals.RADIO_CLK).unwrap()
    );

    let (wifi_interface, controller) =
        esp_wifi::wifi::new_with_mode(init, peripherals.WIFI, WifiStaDevice).unwrap();

    let timg1 = TimerGroup::new(peripherals.TIMG1);
    esp_hal_embassy::init(timg1.timer0);

    let seed = (rng.random() as u64) << 32 | rng.random() as u64;

    let (stack, runner) = embassy_net::new(
        wifi_interface,
        embassy_net::Config::dhcpv4(Default::default()),
        mk_static!(StackResources<3>, StackResources::<3>::new()),
        seed,
    );

    spawner.spawn(wifi_task(controller)).ok();
    spawner.spawn(net_task(runner)).ok();
    spawner.spawn(tcp_task(stack, uart1, led)).ok();

    loop {
        Timer::after(Duration::from_secs(60)).await;
    }
}

#[embassy_executor::task]
async fn wifi_task(mut controller: WifiController<'static>) {
    loop {
        match esp_wifi::wifi::wifi_state() {
            WifiState::StaConnected => {
                controller.wait_for_event(WifiEvent::StaDisconnected).await;
                Timer::after(Duration::from_millis(5000)).await;
            }
            _ => {}
        }
        if !matches!(controller.is_started(), Ok(true)) {
            let client_config = Configuration::Client(ClientConfiguration {
                ssid: SSID.try_into().unwrap(),
                password: PASS.try_into().unwrap(),
                ..Default::default()
            });
            controller.set_configuration(&client_config).unwrap();
            controller.start_async().await.unwrap();
            println!("WiFi started!");
        }
        println!("Connecting to {}...", SSID);
        match controller.connect_async().await {
            Ok(_) => println!("WiFi connected!"),
            Err(e) => {
                println!("Connect failed: {:?}", e);
                Timer::after(Duration::from_millis(5000)).await;
            }
        }
    }
}

#[embassy_executor::task]
async fn net_task(mut runner: Runner<'static, WifiDevice<'static, WifiStaDevice>>) {
    runner.run().await
}
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

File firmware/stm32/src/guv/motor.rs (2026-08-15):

use crate::guv::prime_mover::PrimeMover;
use cortex_m::prelude::_embedded_hal_PwmPin;
use stm32h7xx_hal::{device::TIM1, pwm};

/// DC-motor prime mover: inverted-PWM control of the shaft-drive motor.
/// Inverted: PWM duty=MAX means motor OFF, duty=0 means motor at 100%.
/// The inversion, TIM1 wiring, and max_duty are implementation details hidden
/// behind the PrimeMover interface — the control loop sees only demand 0.0–1.0.
pub struct MotorController {
    pwm: pwm::Pwm<TIM1, 0, pwm::ComplementaryDisabled>,
    max_duty: u16,
    /// Safety clamp — never exceed this demand fraction (0.0–1.0)
    demand_clamp: f32,
    /// Current commanded demand as a fraction (0.0–1.0)
    current_demand: f32,
    enabled: bool,
}

impl MotorController {
    pub fn new(pwm: pwm::Pwm<TIM1, 0, pwm::ComplementaryDisabled>) -> Self {
        let max_duty = pwm.get_max_duty();
        let mut mc = Self {
            pwm,
            max_duty,
            demand_clamp: 1.0,
            current_demand: 0.0,
            enabled: false,
        };
        mc.emergency_off();
        mc
    }

    /// Motor-specific: the raw max PWM duty value (for diagnostics/tests).
    pub fn max_duty(&self) -> u16 {
        self.max_duty
    }

    /// Internal: translate a demand fraction to the inverted PWM duty.
    fn apply_demand(&mut self, fraction: f32) {
        let inverted = self.max_duty as f32 * (1.0 - fraction);
        self.pwm.set_duty(inverted as u16);
    }
}

impl PrimeMover for MotorController {
    fn set_demand(&mut self, demand: f32) {
        if !self.enabled {
            return;
        }
        let clamped = demand.clamp(0.0, self.demand_clamp);
        self.current_demand = clamped;
        self.apply_demand(clamped);
    }

    fn demand(&self) -> f32 {
        self.current_demand
    }

    fn enable(&mut self) {
        self.enabled = true;
    }

    fn disable(&mut self) {
        self.enabled = false;
        self.current_demand = 0.0;
        self.emergency_off();
    }

    fn emergency_off(&mut self) {
        self.current_demand = 0.0;
        self.pwm.set_duty(self.max_duty); // inverted: max duty = motor off
    }

    fn set_max_demand(&mut self, clamp: f32) {
        self.demand_clamp = clamp.clamp(0.0, 1.0);
        if self.current_demand > self.demand_clamp {
            self.set_demand(self.demand_clamp);
        }
    }

    fn max_demand(&self) -> f32 {
        self.demand_clamp
    }

    fn is_enabled(&self) -> bool {
        self.enabled
    }
}

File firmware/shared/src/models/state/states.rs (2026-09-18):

/**
 * honestly thinking about using the yellow led as a indicator light.
 * perhaps 3 second in between the .5 intervals to count
 *  at the very least this should be done to indicate which state it was last in if in fault, certainly
 * fault red
 *
 * generate -> green
 *
 *  pll lock -> flash fast and flash slower up until we lock, then we blink green once ready
 * flash yellur
 */
use serde::{Deserialize, Serialize};

#[derive(Clone, Copy, Debug, Serialize, Deserialize, PartialEq, Eq)]
#[repr(u8)]
pub enum STATE {
    BOOT = 0,
    /**
       init clocks
       gpio
       adc
       ETH interface for MODBUS
       timers,comparators,
       dma
       watchdog (look into this more)
    */
    CALIBRATE = 1,
    /**
        adc,
        ensure sensors are within tolerance,
         gpio ( calling Apolla 9 )
            {
                sending test input for expected output, vise versa
            }
        async hang until we get that the esp32 has fully booted &&
            {
                tells us that we have a lock on api.gaussindustri.es
                we run through all possible messages to confirm correct telemetry will be sent (esp32's own calibration)
                on completion of all neccessary esp32 functions we proceed
            }

    */
    IDLE = 2,
    /// RunConfig received, waiting for Start command
    /**
     * condition green, we've landed on mars
     * sends signal to esp32 to show all systems nominal, waits for esp32 to recieve 200 in order to proceed
     * once we recieve command via interface (from terminal - esp32, thus to demand to change state)
    	*/
    CONFIGURED = 3,
    SPOOLUP = 4,
    /**
    * set target voltages, phase/freq
    * spin up dc motor simulating work being performed on shaft based on below

    as for posterity, ensuring this dovetails into steam power et al:
        closed boiler sys
           fuel type:
               wood/oil
               methane (fartz)
           ensuring superheaters are within tolerant temperatures at all times
               i/o for flash steam valves
           measuring crucible temperature

    */
    EXCITE = 5,
    /**
    * ensure our self excited induction generator (we would upgrade to vfd to not have this mess about in the future)

    */
    PLL_LOCK = 6,
    /**
    * PLL (def): ogase-locked loop has matched it';s output clock's frequency and phase ot the ref (VFD)
        Phase/Frequency detector -> loop filter -> VCO / DCO -> dividers
    */
    READY = 7,
    /**
     * gate not open yet to start using power
     */
    GENERATE = 8,
    /**
     * once signal has been recieved we open gate (or auto if set on spoolup)
     */
    LOAD_REJECTION = 9,
    /// Graceful ramp-down in progress (from any running state via Stop command)
    /**
     * react to drastic change (delta change of amps/load) from 100% to 0%, vise versa
     */
    RAMP_DOWN = 10,
    /// Live manual control from desktop terminal
    MANUAL = 11,
    FAULT = 12,
    /**
    * based on priority from sensors && || gather loop/func of course write the fault enum to be read and sent to overlay
    this should of course send as much info as possible for debugging
    */
    ESTOP = 13,
}

/**
 * once button is pressed (detected in real time)
 * set state back to idle, or rather go down safely or spool down of course send proper telemetry
 */
#[derive(Clone, Copy, Debug, Serialize, Deserialize, PartialEq, Eq)]
pub enum Fault {
    OverVoltage,
    UnderVoltage,
    OverCurrent,
    OverTemp,
    NoExcitation,
    PllUnlock,
    SensorOutOfRange,
    CommLost,
    Overspeed,
    DeadlineMiss,
    LoadRejection,
    EmergencyStop,
}

impl STATE {
    pub fn as_str(self) -> &'static str {
        match self {
            STATE::BOOT => "Boot",
            STATE::CALIBRATE => "Calibrate",
            STATE::IDLE => "Idle",
            STATE::CONFIGURED => "Configured",
            STATE::SPOOLUP => "Spool Up",
            STATE::EXCITE => "Excite",
            STATE::PLL_LOCK => "PLL Lock",
            STATE::READY => "Ready",
            STATE::GENERATE => "Generate",
            STATE::LOAD_REJECTION => "Load Rejection",
            STATE::RAMP_DOWN => "Ramp Down",
            STATE::MANUAL => "Manual",
            STATE::FAULT => "FAULT",
            STATE::ESTOP => "ESTOP",
        }
    }

    /// Is the system in a state where the motor/generator is energized?
    pub fn is_running(self) -> bool {
        matches!(
            self,
            STATE::SPOOLUP
                | STATE::EXCITE
                | STATE::PLL_LOCK
                | STATE::READY
                | STATE::GENERATE
                | STATE::LOAD_REJECTION
                | STATE::CALIBRATE
                | STATE::MANUAL
                | STATE::RAMP_DOWN
        )
    }

    /// Is it safe to accept a Configure command?
    pub fn accepts_configure(self) -> bool {
        matches!(self, STATE::IDLE | STATE::CONFIGURED)
    }

    /// Is it safe to accept a Start command?
    pub fn accepts_start(self) -> bool {
        matches!(self, STATE::CONFIGURED)
    }
}

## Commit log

2025-07-07 Init commit – charter, diagrams, CI, docs
2025-07-09 Added ESP32 Reference Material
2025-10-26 configured linker scripts, simple led blink test
2025-10-26 fixed ld2 not blinking
    [main.rs]
2025-12-11 updated from c/cpp branch
    [ACS772LCB-050B-PFF-T.step, INA240A1PWR.step, P0008A.iges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]
2026-01-15 updated state mod.rs, embedded boot sequence in it's respective file, refined main.rs
    [states.kicad_sch]
2026-01-20 implemented basic logic for pwm for motor spin
2026-02-24 added relay pin & basic safety functionality
2026-03-11 switched to probe-rs for flash/defmt, fixed u64 mismatch in mono timing, fixed negative rpm
    [0_boot.rs, main.rs]
2026-03-11 initialized esp32 logic & build, cleaned config for stm32
2026-03-12 added LED indication for rx (esp32)
2026-03-12 implemented basic UART handshake to ensure stm32 will wait for esp32, or vise versa
2026-03-12 implemented STM32 → UART → ESP32 → WiFi → TCP datapipline
2026-03-17 updated to use data pipeline: STM32 → UART → ESP32 → TCP → Server → SurrealDB
2026-03-22 updated readme to reflect current system
2026-05-28 added motor generics, prelude for granular control of trials/running state, live control, updated models to reflect changes
2026-07-13 updated stm32 to take live parameters and presets
2026-07-29 added calibration prims, wired into state machine
2026-08-01 fixed esp32 COBS protocol for calibration payload to server, tuned stm32 calibration points/struct
    [main.rs, telemetry.rs]
2026-08-01 tuned calibration points for improved k value accuracy & precision
2026-08-13 updated README & documentation
    [master_schematic.kicad_sch, states.kicad_sch]
2026-08-15 refactored/formalized with cobs/postcard re-sync for esp32 & stm32, adding redundancy
2026-08-15 Generalized Prime mover for turbine in the future, impl motor against prime mover
2026-08-19 updated master schematics, added IV ADC schematic sheet
    [STM32.kicad_sch, adc_measurments.kicad_sch, master_schematic.kicad_sch]
2026-08-19 updated master schematics
    [STM32.kicad_sch, master_schematic.kicad_sch]
2026-08-31 created ads131m04 breakout V1
    [CB3LV-3I-8M192000.step, breakout.kicad_pcb, breakout.kicad_sch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]
2026-09-14 added adc, load wiring/state machine, increased telemetry cobs buffer, added lots of images for the website
    [breakout-B_Cu.gbr, breakout-B_Mask.gbr, breakout-B_Paste.gbr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]
2026-09-20 updated adc measurements to fit phase alignment goal
2026-09-24 created unified schematic for sensing
    [AMC1311BDWVR.step, DWV0008A.iges, master_sense_buses.kicad_sch]
2026-09-24 added switch for reference phase 115v-230v
    [master_sense_buses.kicad_sch]
2026-09-24 updated schematic/footprints, updated pcb
    [master_sense_buses.kicad_sch]
2026-09-25 sorted components on pcb
    [master_sense_buses.kicad_pcb]
2026-09-25 updated PCB Rev1.0
    [master_sense_buses.kicad_pcb, master_sense_buses.kicad_sch]
2026-09-25 created gerbers
    [master_sense_buses-B_Cu.gbr, master_sense_buses-B_Mask.gbr, master_sense_buses-B_Paste.gbr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]
